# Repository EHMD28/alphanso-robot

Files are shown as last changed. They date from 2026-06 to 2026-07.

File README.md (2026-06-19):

# Alphanso Rover

Alphanso is first robot I designed and created on my own (hence the name). Alphanso has a 4-wheel mecanum drivetrain and is controlled via bluetooth using a PS4 controller. I later plan to create another rover with more features, but I consider this project very successful for a first attempt.

## Setup

The chassis for Alphanso was 3D printed. Since it's wide and flat, it would have made more sense to cut it out of another material, but I didn't have any of the necessary tools on hand. The CAD model for the chassis is available on Onshape [here](https://cad.onshape.com/documents/276a8e7378f0b6225af4305d/w/07466e83f2c78b557cda318c/e/847e4e1f577a4bce06d5f762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), and the full assembly is available [here](https://cad.onshape.com/documents/276a8e7378f0b6225af4305d/w/07466e83f2c78b557cda318c/e/763026777684ef0bfcde7d5e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).

### Bill of Materials

| Part | Count |
| --- | ----- |
| DOIT-ESP32-DEVKIT_V1 Board | 1 |
| Half-sized Breadboard | 2 |
| 7.4 V Li-ion Battery | 1 |
| T-Plug Connector | 1 |
| LM2596 Buck Converter Module | 1 |
| TB6612FNG Motor Driver Breakout Board | 2 |
| TT Motor | 4 |
| Mecanum Wheel (2 Left and 2 Right) | 4 |
| PS4 Controller | 1 |

_Note: This board is a bit too wide for a standard breadboard, so it's necessary to connect two breadboards together in such a way that there is only one column of pins exposed on each side._

### Wiring

A schematic can be found [here](./schematic/alphanso-rover.pdf). The image below is a reference and not intented to be used as a wiring diagram.

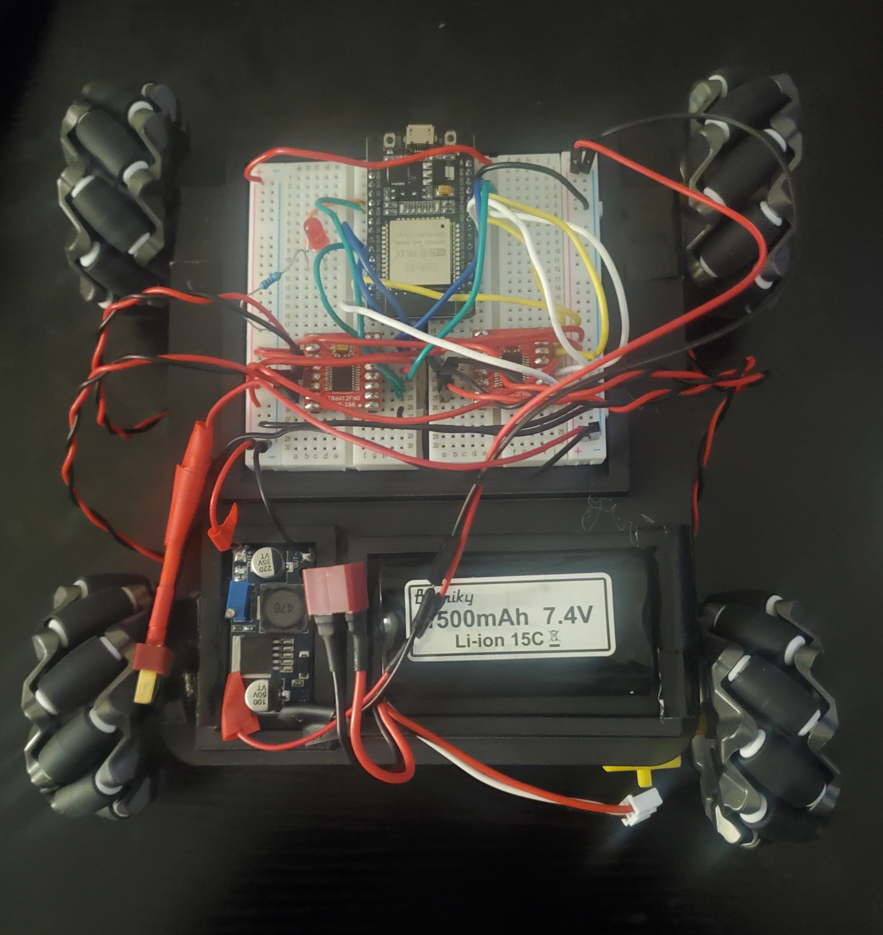
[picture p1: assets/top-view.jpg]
Top view of the robot


### Programming

The full source code can be found in [main.cpp](./src/main.cpp). The code has one dependency: [PS4Controller](https://github.com/aed3/PS4-esp32). This project was developed using Platformio, so it will be easiest use an IDE with the Platformio extension installed to upload the code to your board. You could also install the library using the Arduino IDE and upload the code that way.

You need to change the `PS4_MAC_ADDRESS` variable to match the bluetooth MAC address of the device the controller is paired with. I did this by pairing the controller to my laptop and using my laptop's address, but you should also be able to use the PS4 address directly. Just make sure that controller isn't paired to anything. 

### Control

The left joystick is used for translation, where the side opposite the battery indicates the front. The right joystick is used for rotation, where left is CCW rotation and right is CW rotation. The status LED will blink until the controller is connected, at which point it will turn solid.

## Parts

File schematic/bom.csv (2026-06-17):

Reference | Qty | Value | DNP | Exclude from BOM | Exclude from Board | Footprint | Datasheet
BT1 | 1 | 7.7 V |  |  |  |  | ~
D1 | 1 | Red |  |  |  |  | ~
M1,M2,M3,M4 | 4 | TT Motor (Adafruit #3777) |  |  |  |  | ~
R1 | 1 | 470Ω |  |  |  |  | ~
U1 | 1 | ESP32-DEVKIT-V1 |  |  |  | ESP32-DEVKIT-V1:MODULE_ESP32_DEVKIT_V1
U2,U3 | 2 | TB6612FNG |  |  |  | Package_SO:SSOP-24_5.3x8.2mm_P0.65mm | https://toshiba.semicon-storage.com/us/product/linear/motordriver/detail.TB6612FNG.html
U4 | 1 | LM2596S-5 |  |  |  | Package_TO_SOT_SMD:TO-263-5_TabPin3 | http://www.ti.com/lit/ds/symlink/lm2596.pdf

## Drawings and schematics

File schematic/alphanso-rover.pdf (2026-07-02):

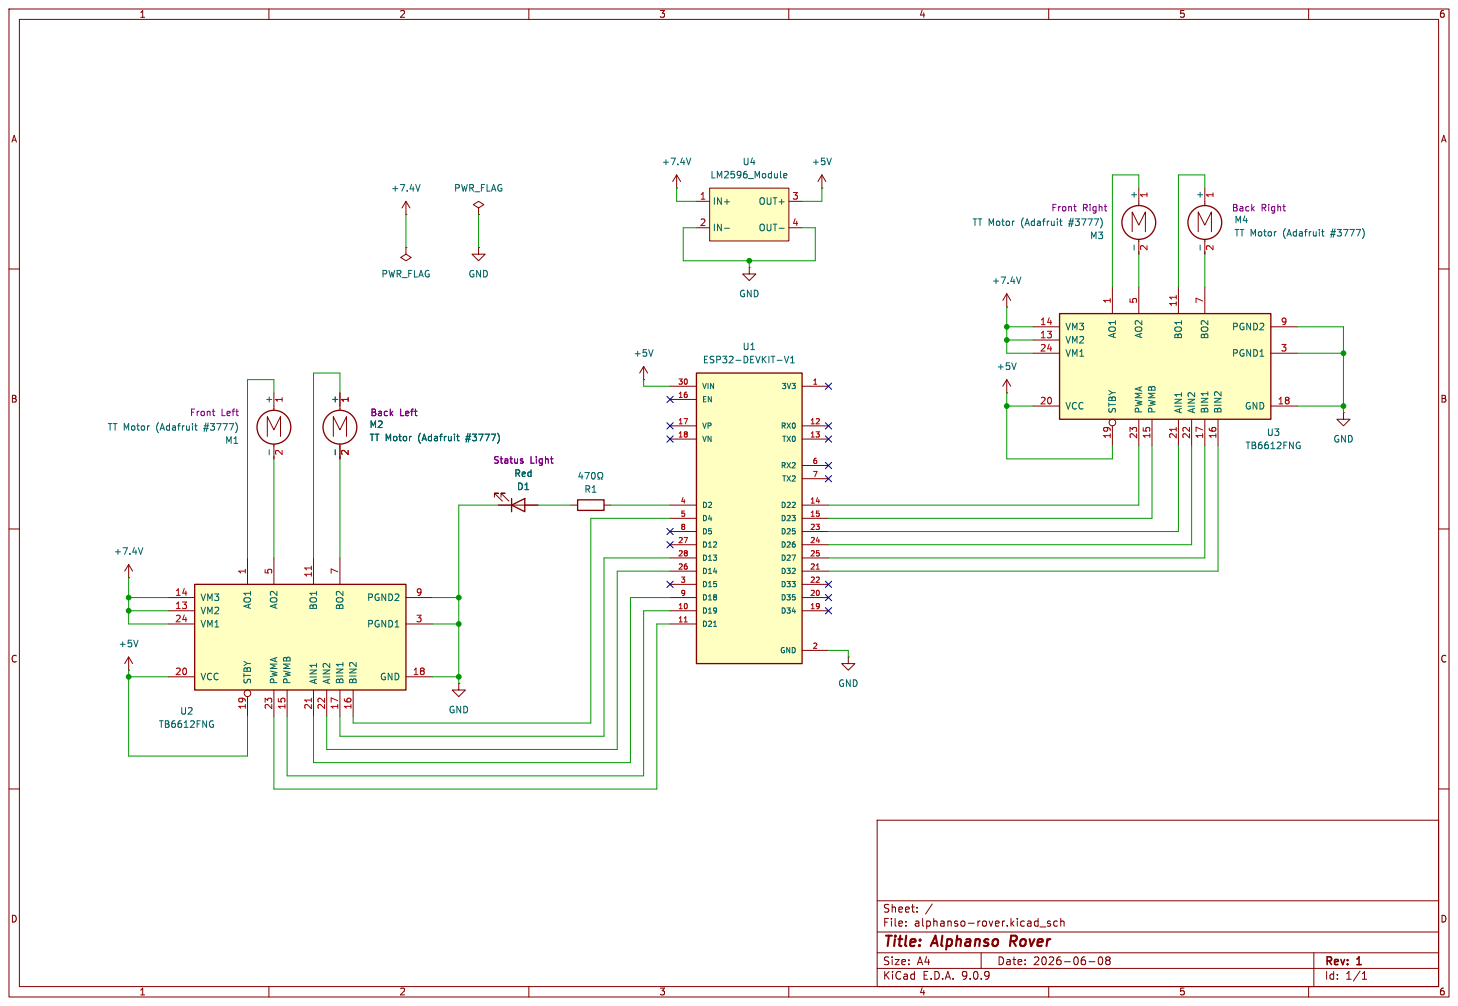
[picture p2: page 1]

-2 M4 TT Motor (Adafruit #3777) Back Right +7.4V GND

-2 M3 TT Motor (Adafruit #3777) Front Right +5V GND

-2 M2 TT Motor (Adafruit #3777) Back Left GND STBY 19 PWMA 23 PWMB 15 AIN1 21 AIN2 22 BIN1 17 BIN2 16 VCC 20 GND 18 VM1 24 PGND1 3 VM2 13 VM3 14 PGND2 9 AO1

-2 M1 TT Motor (Adafruit #3777) Front Left GND

Id: 1/1 Title: Alphanso Rover File: alphanso-rover.kicad_sch Sheet: /

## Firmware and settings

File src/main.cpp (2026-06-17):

#include <Arduino.h>
#include <PS4Controller.h>

/* -------- Motor Utilities -------- */

constexpr int MOTOR_PWM_FREQUENCY = 20000; // 20 kHz
constexpr int MOTOR_RESOLUTION = 8; // 8-bits [0, 255]
constexpr int MAX_MOTOR_PWM = 255;

/**
 * An interface for controlling a motor channel using the TB6612FNG motor
 * driver. Assumes that the STBY is externally pulled HIGH.
 */
class MotorChannel {
    private:
        uint8_t in1_pin;
        uint8_t in2_pin;
        uint8_t pwm_channel;
        bool is_reversed;
        

        void drive_cw(uint8_t duty_cycle) {
            digitalWrite(in1_pin, HIGH);
            digitalWrite(in2_pin, LOW);
            ledcWrite(pwm_channel, duty_cycle);
        }
        
        void drive_ccw(uint8_t duty_cycle) {
            digitalWrite(in1_pin, LOW);
            digitalWrite(in2_pin, HIGH);
            ledcWrite(pwm_channel, duty_cycle);
        }

    public:
        MotorChannel(uint8_t in1_pin, uint8_t in2_pin, uint8_t pwm_pin, uint8_t channel, bool is_reversed) {
            this->in1_pin = in1_pin;
            this->in2_pin = in2_pin;
            this->pwm_channel = channel;
            this->is_reversed = is_reversed;

            pinMode(in1_pin, OUTPUT);
            pinMode(in2_pin, OUTPUT);
            pinMode(pwm_pin, OUTPUT);

            ledcAttachPin(pwm_pin, channel);
            ledcSetup(channel, MOTOR_PWM_FREQUENCY, MOTOR_RESOLUTION);

            stopMotor();
        }

        /**
         * Brakes the motor and sets the duty cycle to 0.
         */
        void stopMotor() {
            digitalWrite(in1_pin, LOW);
            digitalWrite(in2_pin, LOW);
            ledcWrite(pwm_channel, 0);
        }
        
        /**
         * @param speed The speed and direction to drive the motor. Value: [-255, 255].
         */
        void driveMotor(int16_t speed) {
            speed *= is_reversed ? -1 : 1;
            /* CCW rotation is positive */
            if (speed > 0) {
                drive_ccw(speed);
            } else if (speed < 0) {
                drive_cw(-speed);
            } else {
                stopMotor();
            }
        }
};

/* -------- Status LED -------- */
constexpr uint8_t STATUS_LED_PIN = 2;
constexpr uint16_t SHORT_DELAY = 2000;

/* -------- Motor Driver 1 (Left Side) -------- */
constexpr uint8_t DRIVER1_BIN2_PIN = 4;
constexpr uint8_t DRIVER1_BIN1_PIN = 13;
constexpr uint8_t DRIVER1_AIN2_PIN = 14;
constexpr uint8_t DRIVER1_AIN1_PIN = 18;
constexpr uint8_t DRIVER1_PWMB_PIN = 19;
constexpr uint8_t DRIVER1_PWMA_PIN = 21;

/* -------- Motor Driver 2 (Right Side) -------- */
constexpr uint8_t DRIVER2_BIN2_PIN = 32;
constexpr uint8_t DRIVER2_BIN1_PIN = 27;
constexpr uint8_t DRIVER2_AIN2_PIN = 26;
constexpr uint8_t DRIVER2_AIN1_PIN = 25;
constexpr uint8_t DRIVER2_PWMB_PIN = 23;
constexpr uint8_t DRIVER2_PWMA_PIN = 22;

/* -------- Motor PWM Channels -------- */
constexpr uint8_t FRONT_LEFT_CHANNEL = 1;
constexpr uint8_t BACK_LEFT_CHANNEL = 2;
constexpr uint8_t FRONT_RIGHT_CHANNEL = 3;
constexpr uint8_t BACK_RIGHT_CHANNEL = 4;

/* -------- Drivetrain -------- */
/* The last argument to each constructor is whether or not the motor is reversed. */
MotorChannel front_left_motor = MotorChannel(DRIVER1_AIN1_PIN, DRIVER1_AIN2_PIN, DRIVER1_PWMA_PIN,
                                        FRONT_LEFT_CHANNEL, false);
MotorChannel back_left_motor = MotorChannel(DRIVER1_BIN1_PIN, DRIVER1_BIN2_PIN, DRIVER1_PWMB_PIN,
                                        BACK_LEFT_CHANNEL, false);
MotorChannel front_right_motor = MotorChannel(DRIVER2_AIN1_PIN, DRIVER2_AIN2_PIN, DRIVER2_PWMA_PIN,
                                        FRONT_RIGHT_CHANNEL, true);
MotorChannel back_right_motor = MotorChannel(DRIVER2_BIN1_PIN, DRIVER2_BIN2_PIN, DRIVER2_PWMB_PIN,
                                        BACK_RIGHT_CHANNEL, false);

/**
 * Drive the robot using inputs from a joystick.
 * 
 * @param fwd The speed of the robot in the forwards-backwards direction.
 * Forwards is positive, backwards is negative. Range: [-1.0, 1.0].
 * @param strafe The speed of the robot in the side-to-side direction.
 * Right is positive, left is negative. Range: [-1.0, 1.0].
 * @param rot The speed to rotate the robot. Clockwise is positive (TODO: Check
 * this). Range: [-1.0, 1.0].
 */
void drive(double fwd, double strafe, double rot) {
    // Front left motor power
    double fl = fwd + rot + strafe;
    // Front right motor power
    double fr = fwd - rot - strafe;
    // Back left motor power
    double bl = fwd + rot - strafe;
    // Back right motor power
    double br = fwd - rot + strafe;
    /* Normalize motor powers if any of them exceed 1.0 in magnitude. */
    double max_val = max({abs(fl), abs(fr), abs(bl), abs(br)});
    if (max_val > 1.0) {
        fl /= max_val;
        fr /= max_val;
        bl /= max_val;
        br /= max_val;
    }
    /* Convert from percentages to duty cycles */
    int16_t fl_speed = fl * MAX_MOTOR_PWM;
    int16_t fr_speed = fr * MAX_MOTOR_PWM;
    int16_t bl_speed = bl * MAX_MOTOR_PWM;
    int16_t br_speed = br * MAX_MOTOR_PWM;
    /* Drive each motor */
    front_left_motor.driveMotor(fl_speed);
    front_right_motor.driveMotor(fr_speed);
    back_left_motor.driveMotor(bl_speed);
    back_right_motor.driveMotor(br_speed);
}

void test_drive() {
    front_left_motor.driveMotor(100);
    delay(SHORT_DELAY);
    front_left_motor.stopMotor();
    front_right_motor.driveMotor(100);
    delay(SHORT_DELAY);
    front_right_motor.stopMotor();
    back_right_motor.driveMotor(100);
    delay(SHORT_DELAY);
    back_right_motor.stopMotor();
    back_left_motor.driveMotor(100);
    delay(SHORT_DELAY);
    back_left_motor.stopMotor();
}

/* -------- Controller -------- */
// This is the of the device the controller is paired with (not the controller itself).
const char* PS4_MAC_ADDRESS = "44:85:00:A0:09:0F";
// Through my testing, all values in the range of [-10, 10] (out of [-128, 127]) can be ignored as stick drift.
constexpr int8_t JOYSTICK_DEADBAND = 10;
constexpr int8_t MAX_JOYSTICK_INPUT = 128;

int8_t apply_deadband(int8_t input) {
    return (abs(input) <= JOYSTICK_DEADBAND) ? 0 : input;
}

void setup() {
    pinMode(STATUS_LED_PIN, OUTPUT);
    PS4.begin(PS4_MAC_ADDRESS);    
    while (!PS4.isConnected()) {
        digitalWrite(STATUS_LED_PIN, HIGH);
        delay(500);
        digitalWrite(STATUS_LED_PIN, LOW);
        delay(500);
    }
    digitalWrite(STATUS_LED_PIN, HIGH);
}

void loop() {
    /* Raw joystick input values. Right is +x, left is +y, and range is [-128, 127]. */
    int8_t raw_lx = PS4.LStickX();
    int8_t raw_ly = PS4.LStickY();
    int8_t raw_rx = PS4.RStickX();
    /* Map raw inputs into percentages onto the interval [-1.0, 1.0]. */
    double lx = (double) apply_deadband(raw_lx) / MAX_JOYSTICK_INPUT;
    double ly = (double) apply_deadband(raw_ly) / MAX_JOYSTICK_INPUT;
    double rx = (double) apply_deadband(raw_rx) / MAX_JOYSTICK_INPUT;
    /* Drive robot using the controller inputs. Left joystick controls translation,
    right joystick controls rotation. */
    drive(ly, lx, -rx);
    delay(100);
}

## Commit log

2026-06-05 updated schematic and gitignore
    [alphanso-rover.kicad_sch]
2026-06-07 initialized platformio
    [alphanso-rover.kicad_sch]
2026-06-07 added (not tested) basic motor code
2026-06-08 added all motors
    [alphanso-rover.kicad_sch]
2026-06-12 reversed motors
2026-06-17 reversed rotation to match joystick
    [main.cpp]
2026-06-17 added readme and bom
    [alphanso-rover.csv, bom.csv]
2026-06-19 added assembly to readme
2026-07-02 updated power net schematics
    [alphanso-rover.kicad_sch]
